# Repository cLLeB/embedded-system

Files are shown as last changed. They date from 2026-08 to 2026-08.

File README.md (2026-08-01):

# Smart Socket with Adaptive Time-of-Use Scheduling

**Project #38** — Arduino Uno. Cuts wall power when a charging device reaches full charge,
so it never trickle-charges and the battery lasts longer.

Status: **working on real 230 V mains.** 123/123 core tests passing, 41% flash / 40% RAM on
the Uno. Confirmed on hardware: a laptop charged to 95%, the socket detected the taper, cut
wall power and latched.

**Build it by following [`docs/FINAL_BUILD.md`](docs/FINAL_BUILD.md)** — that is the current
guide, step by step from bare parts to a working socket. `BUILD_GUIDE.md` and
`docs/STAGE2.md` describe the earlier low-voltage bench rig (18650 + resistor bank) that was
used to prove the firmware, and are kept for the reasoning only.

---

## Open it in Arduino IDE

1. **File → Open…** → select `SmartSocket/SmartSocket.ino`
2. **Tools → Board →** Arduino AVR Boards → **Arduino Uno**
3. **Sketch → Verify**

That is the whole migration. No project files to convert, no paths to fix. The `src/`
subfolder compiles automatically — that is a standard Arduino sketch layout, not a trick.

### The one dependency

**LiquidCrystal_I2C** (already installed on this machine, v1.1.2).

On any other machine: **Tools → Manage Libraries…** → search `LiquidCrystal I2C` → install
the one by *Frank de Brabander*.

Everything else — the algorithm, the state machine, the maths — is in this repo. No other
libraries.

---

## Wiring

| Uno pin | Connects to | Notes |
|---|---|---|
| **A0** | ACS712 `OUT` | analog signal |
| **5V** | ACS712 `VCC`, LCD `VCC`, relay `VCC` | |
| **GND** | ACS712 `GND`, LCD `GND`, relay `GND` | all grounds common |
| **A4** | LCD `SDA` | fixed I2C pin on the Uno |
| **A5** | LCD `SCL` | fixed I2C pin on the Uno |
| **D2** | Button 1 → other leg to **GND** | NEXT (cycle screens) |
| **D3** | Button 2 → other leg to **GND** | ACTION (reset / hold to force off) |
| **D7** | Relay `IN` | |
| **D8** | Buzzer `+` | buzzer `−` to GND |

**Buttons need no resistors.** They use the Uno's internal pull-ups, so each button just
bridges its pin to GND.

The **load** passes through the ACS712's screw terminals (in series) and through the relay's
COM/NO contacts.

### If the relay behaves backwards

Most cheap 1-channel boards are active-LOW, which is the default. If yours clicks the wrong
way, set `RelayActiveLow = false` in `SmartSocket/src/hal/HalPins.h`.

### If the LCD stays blank

The backpack address is usually `0x27`, occasionally `0x3F`. Change `LcdI2cAddress` in
`SmartSocket/src/core/Config.h`. If it is lit but shows nothing, turn the contrast
potentiometer on the back of the backpack.

---

## AC or DC — read this before wiring

Near the top of `SmartSocket.ino`:

```cpp
#define SENSOR_MODE_AC 1   // 1 = 230 V mains (true RMS)   0 = low-voltage DC bench test
```

This is **not** a cosmetic setting. AC current is a sine wave that averages to roughly zero
regardless of load, so the two modes use genuinely different maths:

- **AC (1)** — samples across whole 50 Hz cycles and computes true RMS. Correct for Ghana
  mains. **This is the default, and what the finished socket runs.**
- **DC (0)** — averages samples. For the old low-voltage bench rig only.

Run DC mode on mains and the socket reads an empty socket while a laptop charges. Run AC
mode on DC and it reads noise. **Match it to what you actually wired.**

## Safety

**230 V AC can kill you.** The mains side of this project is a genuine shock and fire
hazard, and no amount of firmware changes that.

- Bench-test on **low-voltage DC** first (`SENSOR_MODE_AC 0`).
- Mains work belongs in a proper enclosure, with adequate spacing, under supervision.
- Never work on it live.

The firmware fails safe — the relay is opened before anything else at boot and on any fault
— but firmware cannot make mains wiring safe.

---

## Using it

On boot the LCD shows `Calibrating...` for a moment while the sensor's zero point is
measured. Then it sits at `READY` with power on, waiting.

Plug a device in → short beep → `CHARGING`, with live current and elapsed time. When the
device fills up and its draw tapers off, the socket confirms the drop is real, cuts power,
beeps three times, and shows:

```
FULL - POWER CUT
Press ACTION
```

It **stays** cut. It will not re-arm on its own — auto-rearming would restart the exact
trickle charging this project exists to prevent. Press ACTION to re-arm.

If you re-arm without unplugging, the socket notices the device is still full (it never
draws a real charging current) and cuts it again after about a minute, rather than
trickle-charging it forever.

**Buttons**

| Action | Effect |
|---|---|
| **NEXT**, tap | Cycle screens: Status → Detail → Stats |
| **ACTION**, tap | Clear a cutoff or fault, re-arm |
| **ACTION**, hold 1.5 s | Force power off / back on |

**Screens**

```
Status              Detail              Stats
CHARGING   1.24A    Cut at     0.60A    Cutoffs        7
02:15:33  pk2.00    Taper 30%    n=7    Saved     12h30m
```

---

## What "adaptive" means here

The title says *time-of-use*, but the parts list has no RTC — the board cannot know the
clock time, let alone electricity tariff hours. The brief's description never mentions
tariffs either. It describes exactly one behaviour: measure the power, catch the drop that
means full, cut the wall.

So the *time of use* being adapted to is **the device's**, and *adaptive* means it learns:

- **Within a session** — the cutoff threshold is a fraction of the peak current this device
  actually drew, so it scales itself to a phone (~0.5 A) or a laptop (~2 A) with nothing to
  configure.
- **Across sessions** — after each successful cutoff it records where the taper really
  happened and blends it into a learned value in EEPROM. Over a few charges it converges on
  *your* device's real taper point.

Full reasoning in `docs/superpowers/specs/2026-07-17-smart-socket-design.md`.

---

## How the code is laid out

```
SmartSocket/
  SmartSocket.ino        wires the hardware to the logic; setup() and loop()
  src/core/              the logic. No Arduino.h anywhere. Tested on the PC.
    ChargeAnalyzer       the full-charge algorithm
    SocketController     the state machine that owns the relay
    CurrentMath          ADC counts -> milliamps, integer RMS
    UiPresenter          state -> two 16-char lines
    ProfileCodec         EEPROM record framing + CRC
    ButtonDebouncer, BuzzerDriver, Format, Config, Types, Interfaces
  src/hal/               the hardware. The only place Arduino.h appears.
test/                    95 tests + fakes. Arduino IDE never sees this folder.
docs/                    design spec
```

The core talks to hardware only through interfaces (`src/core/Interfaces.h`). That is what
makes two useful things possible at once: hardware can be swapped by touching one file in
`src/hal/`, and the whole algorithm can be tested with a fake clock — a three-hour charge
session runs in microseconds, so the 90-second confirmation window costs nothing to test.

## Running the tests

```powershell
powershell -ExecutionPolicy Bypass -File test\run_tests.ps1
```

Needs Visual Studio Build Tools with the C++ workload (already installed here). No test
framework to install.

The script compiles `src/core` **only** — never `src/hal`. That is deliberate: if anyone
ever adds an Arduino include to the core, the tests stop compiling and the mistake surfaces
immediately instead of at migration time.

## Tuning

Everything adjustable is in `src/core/Config.h`. The two that matter:

| Constant | Default | Meaning |
|---|---|---|
| `TaperConfirmMs` | 90 s | How long current must stay low before cutting. **Lower is dangerous** — it is the guard against cutting a laptop's power on a momentary dip. Raising it only wastes a little energy. |
| `TaperRatioDefaultPct` | 30 % | Starting cutoff point as a fraction of peak, before anything is learned. |
| `TaperMarginPct` | 130 % | How far the cutoff threshold sits above the *learned* ratio. **Do not set this to 100.** The margin is what stops the learning from eating itself — see the comment on it in `Config.h`. |

## Known limits — all measured, not assumed

- **It cannot see a phone.** Measured on this hardware: a phone charging draws **0.02 A** on
  230 V, which is the same as an empty socket reads. 20 mA is 0.4% of the ACS712-**5A**'s
  range and 0.76 of one ADC count, so no threshold can separate the signal from the noise.
  Laptop-class loads (0.13–0.16 A) work reliably. This is the specified sensor's resolution,
  not an algorithm fault — the same firmware on a 1 A part, or a shunt and INA219, resolves
  both. `ICurrentSensor` exists so that swap costs one file.
- **Resolution is better than the datasheet arithmetic suggests.** One ADC count is 26 mA,
  but the AC RMS window averages ~500 samples, and the measured noise pedestal on an empty
  socket is **under 0.02 A**. Averaging drives quantisation noise below a single count.
- **The adaptive learning is currently inert.** `TaperFloorMa` (100 mA) is larger than the
  peak-derived threshold at these currents, so the floor decides every cutoff and the learned
  ratio never changes the outcome. The learning is correct and tested; it just has no room to
  act at 230 V with this sensor. On the 3.7 V rig, where peaks were 370 mA, it governed.
- **One profile.** The socket learns one device profile, not one per device. Alternating
  devices makes the learned ratio drift between them. The within-session peak-scaling still
  handles both correctly; only the cross-session learning blurs.
- **The relay is the weak part.** A switch-mode charger's inrush is tens of amps for a few
  milliseconds, and a 10 A relay switching into that repeatedly can micro-weld its contacts.
  The firmware now detects this (see below) rather than claiming to have cut power it hasn't.

## What makes it "smart" beyond the cutoff

- **Automatic recovery.** The sensor is downstream of the relay, so an open relay leaves the
  socket blind — it cannot tell an empty socket from a full laptop. Rather than demand a
  button press, it closes the contacts for 8 s every 15 min (device still present) or 60 s
  (socket empty) and resumes only on a real charging current. Not auto-rearming: it stays
  closed only on positive evidence.
- **Relay verification.** `setClosed(false)` is a command, not a measurement. The socket keeps
  sampling while cut, and if current is still flowing 3 s later it raises `! RELAY STUCK !`
  instead of displaying `FULL - POWER CUT` over a live outlet.
- **It cannot silently freeze.** `Wire` has a 25 ms timeout so I2C noise from the relay
  cannot lock the bus, and a 4 s watchdog resets the chip if `loop()` ever stops — on reset
  the relay is opened before anything else. A hang used to leave the relay wherever it was,
  which on a mains socket means power stuck **on**.
- **The zero offset is tracked, not calibrated once.** The ACS712's offset drifts with
  temperature and rail loading; frozen at boot it walked far enough in two minutes to fake a
  0.10 A load on an empty socket. Each 60 ms window now re-derives it from the sample mean,
  which over whole mains cycles is the offset whether a load is present or not.

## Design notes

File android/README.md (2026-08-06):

# Smart Socket — Android app

Talks to the socket over Bluetooth Classic (SPP), shows what it is doing, and
tells it when to cut power.

**Runs with no hardware.** The connect screen has a demo that drives every screen
from a simulated socket, so the app can be developed and shown before an HC-05
exists.

---

## Build

```powershell
cd android
.\gradlew.bat assembleDebug
```

The APK lands in `app/build/outputs/apk/debug/app-debug.apk`.

Toolchain: JDK 17+, Gradle 8.11.1, AGP 8.9.1, Kotlin 2.0.21, compileSdk 35,
minSdk 26. `local.properties` points at the SDK.

---

## What it does

| | |
|---|---|
| **Live status** | State, current, peak, and how close the current is to the cutoff threshold |
| **Control** | Cut power, re-arm, probe now — the same three commands the buttons give |
| **Charge limit** | Stop charging **this phone** at 80 / 90 / 100% |
| **Notifications** | Tells you when power was cut, even with the app closed |
| **History** | Every cutoff, with peak, taper point and duration, plus a chart |
| **Export** | The history as a CSV, out through the share sheet |
| **Reconnects itself** | Rebuilds a dropped link for about eight minutes before giving up |
| **Demo mode** | A simulated socket, for when the real one is in another room |

### The charge limit is the point

A phone charging on 230 V draws about **20 mA**, which is inside the ACS712-5A's
noise. The socket genuinely cannot tell a charging phone from an empty outlet —
see "Known limits" in the root README.

But the phone knows its own battery. So the app watches `BatteryManager`, and
when the level crosses the limit it sends `C`. The socket stops having to
*infer* the charge state because it is *told*.

An 80% limit is also what battery-longevity practice recommends, which is the
premise of the whole project.

---

## Architecture

```
data/
  SocketStatus.kt     the model, and SocketState mirroring Types.h ordinals
  StatusParser.kt     decodes one "S,..." line, or returns null
  SocketTransport.kt  the interface
  BluetoothTransport  real link, RFCOMM to an HC-05
  MockTransport       a socket that exists only in software
  ReconnectPolicy.kt  how long to wait before the nth retry
  HistoryStore.kt     the flat file
  HistoryCsv.kt       history rendered for a spreadsheet
  HistoryExport.kt    that CSV into a share intent
ui/
  Theme.kt            the palette
  Components.kt       the shared pieces
  *Screen.kt          splash, onboarding, connect, dashboard
SocketViewModel.kt    state, battery watching, command dispatch
```

### Tests

```powershell
cd android
.\gradlew.bat :app:testDebugUnitTest
```

27 plain JVM tests, no emulator and no Robolectric. Everything worth testing —
the wire format, the reconnect schedule, the export — was written with no
Android in it so that it could be tested this way, which is the same split that
lets the firmware's `src/core` run on a PC.

**`SocketTransport` has two implementations for the same reason the firmware has
`ICurrentSensor`:** so the thing above it can be built and tested without the
hardware below it. `MockTransport` is not a stub returning canned values — it
runs the real sequence (settle, charge, taper, cut, wait, probe) at 20× speed,
which also makes states that are slow to reach on real hardware reachable in
seconds.

### Parsing is strict on purpose

`StatusParser` returns `null` for anything it does not fully understand. A
Bluetooth link drops mid-line every time the phone moves out of range, so partial
and corrupt lines are the normal case — and a half-parsed line would show a
number that never existed.

### An open socket is not a Smart Socket

`BluetoothTransport.connect` does not report success when the RFCOMM socket
opens. It sends `?` and waits for one line it can parse, up to three times.

Every bonded device that speaks SPP accepts a connection, and a swapped TX wire
or a module left at the wrong baud rate connects *perfectly* and then says
nothing at all. Without the handshake that arrives as a dashboard full of zeroes
with no clue which of the two it was. With it, the two cases are told apart by
whether any bytes arrived before the timeout:

| What happened | What the user is told |
|---|---|
| No bytes at all | Check `TXD` → Arduino pin 0, and that the socket is powered |
| Bytes, but nothing parses | Almost always the baud rate — the firmware uses 9600 |

### Reconnecting

A dropped link is rebuilt on a schedule that doubles from 2 s to a one-minute
ceiling, for twelve attempts — about eight minutes. Two cases pull in opposite
directions: a radio glitch wants a retry immediately, and someone who walked
into another room wants one much later. The ceiling serves the second without
making the first wait.

It **gives up** rather than retrying forever, and posts a notification when it
does. A foreground notification the user cannot dismiss, sitting over a socket
that has been switched off at the wall, is worse than an honest "lost it".

`LinkState.Reconnecting` is a separate state from `Connecting` because the two
mean opposite things to the UI: a reconnect must **not** throw the user back to
the device picker and must **not** release the foreground service. The dashboard
keeps the last readings on screen, labelled as the last ones, and disables the
command buttons — a button that looks like it worked and did not is worse than a
dead one on a device that switches mains.

---

## Design

**Gold on black.** Three golds, four blacks, and warm off-white rather than pure
white — `#FFFFFF` against gold reads cold and makes the gold look green.

**Dynamic colour is deliberately disabled.** On Android 12+ `dynamicDarkColorScheme`
derives the palette from the user's wallpaper, which usually lands on Material's
lavender-purple default. That would repaint the app in someone else's colours.

**No ripples.** Material's default ripple is a grey wash that reads as a smear on
gold; the buttons signal touch with colour instead.

The one chart is the taper bar on the dashboard — the whole product is "watch
this fall past that line", and a number alone does not show how close it is.

---

## Bluetooth notes

- **Classic SPP, not BLE.** An HC-05 is a Bluetooth 2.0 device. This will never
  work on iOS, which blocks SPP without MFi certification
- **Pair in Android's settings first.** The app lists bonded devices; it does not
  run discovery. Default HC-05 code is `1234` or `0000`
- **Android 12+ needs runtime `BLUETOOTH_CONNECT` / `BLUETOOTH_SCAN`.** Below 31
  the legacy manifest permissions are granted at install, so the request is
  skipped rather than failed — most tutorials predate this split and get it wrong

---

## Staying alive in the background

`SocketRepository` is held by the **Application**, not a ViewModel. That is the
whole trick: a link owned by a ViewModel dies with the screen, and can only
notify someone already looking at it.

`SocketService` is a foreground service that keeps the process alive while a
connection is up. It does not own the link — it exists so Android does not kill
the process, and so there is something to look at while it runs. Started on
connect, stopped on disconnect, because a notification the user cannot dismiss
should only be there while it is buying something.

Android 14 requires a foreground service to declare a type and hold the matching
permission; `connectedDevice` is the honest one here.

`SocketRepository` is also the only place that watches for **transitions**
rather than state — a cutoff notification has to fire on the edge into `Cutoff`,
once, not on every status line that happens to say `Cutoff`.

## History without Room

`HistoryStore` writes comma-separated lines to a file in `filesDir`, newest
first, capped at 60.

Room would bring the KSP plugin, a schema, a DAO and migrations for a table with
four integer columns that will never hold more than 60 rows. The cost is all
ceremony. Reads are one `readLines`, writes one `writeText`, and the format is
legible if anyone wants to look at it.

The chart is bars, not a line: each charge is a discrete event, and a line
between them would imply values in the gaps that were never measured.

**Export** writes the same rows to the cache directory as a CSV and hands it out
through a share intent, so it can go to email, Drive, or anything else with no
storage permission on any Android version. Two time columns: an ISO one for a
human and a millisecond one for a spreadsheet that will not parse it. Rows run
**oldest first**, the reverse of the screen — the newest charge belongs at the
top of a list, but a column a spreadsheet is going to plot has to run forwards.

## Not built yet

- **Connecting to real hardware has never been tested.** The HC-05 is here and
  wired but the first end-to-end run has not happened. Everything else runs

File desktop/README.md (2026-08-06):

# Smart Socket — Windows app

The desktop companion. Same socket, same wire format, same gold-on-black as the
phone app, plus the one thing a laptop can do that a phone cannot: cut power at
**its own** battery percentage.

---

## Why this exists when the socket already works

The socket cuts power on its own. It watches the charge current taper and opens
the relay when it falls far enough below the peak — no app, no phone, no PC.
That is the whole safety-critical path and it is finished.

What it cannot do is know *what percentage* that taper happened at. On a laptop
the taper lands wherever the charger decides, typically the high nineties.

If what you want is to stop at **80%** for the sake of the battery's lifespan,
only Windows knows when that is. So this app asks Windows and sends the cut.

Both cutoffs run at once and do not fight: whichever condition is met first
cuts, and the firmware ignores a `C` for a state it is already in.

| Device | What cuts the power |
|---|---|
| Laptop | The socket's current sensing, **or** this app at your exact percentage |
| The phone running the Android app | That app, at its battery limit |
| Anything else | The socket's current sensing only |

---

## Build and run

Needs the .NET 8 SDK. Nothing else — no Visual Studio.

```powershell
# All 30 core tests. No hardware, no UI, runs in under a second.
dotnet test tests\SmartSocket.Core.Tests\SmartSocket.Core.Tests.csproj

# Debug run.
dotnet run --project src\SmartSocket.App

# The thing you hand to somebody: one self-contained .exe, no runtime needed.
dotnet publish src\SmartSocket.App\SmartSocket.App.csproj -c Release -o dist
```

The published `dist\SmartSocket.exe` is about 68 MB because it carries the .NET
runtime and WPF inside it. That is the deliberate trade: nothing to install, no
"please install .NET 8" step in front of somebody marking the project.

---

## The architecture rule, again

**`SmartSocket.Core` must never reference anything Windows.**

It targets plain `net8.0`, not `net8.0-windows`, so the compiler enforces it —
the same trick as the firmware's `src/core` never including `Arduino.h`, and the
Android app's data layer never importing Android.

That is what lets the wire format, the charge session, the reconnect schedule
and the CSV export be tested with no window, no COM port and no socket.

```
desktop/
  src/SmartSocket.Core/     plain net8.0. Parser, session, reconnect, CSV.
  src/SmartSocket.App/      net8.0-windows. WPF, serial, tray, Win32 battery.
  tests/SmartSocket.Core.Tests/   30 tests, ported case for case from Kotlin.
```

The tests are deliberately ports of the Android app's tests, assertion for
assertion. Two clients that disagree about the wire format would show different
numbers for the same socket, and the tests are what stop that happening
quietly.

---

## Connecting

Both routes to the socket are a COM port at 9600, so there is one transport:

- **USB cable** — the Uno enumerates directly through its CDC/CH340 driver.
- **HC-05** — pair it in Windows Bluetooth settings first. Windows then exposes
  an *outgoing* virtual COM port for it, which is the one to pick.

**An open port is not a Smart Socket.** Windows will happily open a port
belonging to a printer or a GPS dongle, so connecting is not finished until the
socket has answered a `?` with a line the app can parse. The three ways that can
fail are reported separately because they have different fixes:

| The app says | What is wrong |
|---|---|
| "already open in another program" | Close the Arduino IDE's Serial Monitor |
| "opened but never sent anything" | Wrong port, or the socket is not powered |
| "sending data this app cannot read" | Baud rate. The firmware uses 9600 |

Opening a COM port asserts DTR, which **resets the Uno**. That is wanted — it
puts the firmware in a known state — but it is why the handshake tolerates
several seconds of silence before giving up.

---

## Closing the window does not stop it

The window is a view, not the app. Closing it hides it to the tray, because a
socket being watched is the normal state and a window on screen is not. The tray
icon carries the current state in its tooltip, offers **Cut** and **Re-arm**
directly, and **Quit** is the only thing that actually stops it.

This is the desktop counterpart of the phone app's foreground service, and it
exists for the same reason: a cutoff an hour away is no use if it only fires
while somebody is looking at the screen.

Balloon notifications fire on cutoff, on a stuck relay, on a lost link, and when
the app itself cut at your battery limit.

---

## What it stores, and where

`%APPDATA%\SmartSocket\`

| File | What |
|---|---|
| `settings.json` | Battery limit, whether to cut at it, last port used |
| `history.csv` | Completed charges, in the same four-field encoding the Android app writes |

The history encoding is shared deliberately: a file from the phone can be
dropped in here and read, and the exported spreadsheet has identical columns
from both apps, so exports can be concatenated.

---

## Known limits

- **Windows only.** WPF and `GetSystemPowerStatus` are both Win32. The `Core`
  project is portable; nothing above it is.
- **A desktop PC has no battery**, so the percentage cutoff has nothing to act
  on. The app says so and disables the control rather than showing 0%.
- **Reconnect gives up after about eight minutes** (`ReconnectPolicy`), rather
  than retrying forever. A tray icon claiming to watch a socket switched off at
  the wall is worse than an honest "lost it".
- If Windows will not report the battery percentage it returns 255, which the
  app treats as "unknown" and refuses to act on. Guessing there would cut power
  to a machine whose charge it does not know.

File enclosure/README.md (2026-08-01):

> ## ⚠ THIS FILE IS OUT OF DATE — DO NOT PRINT FROM IT
>
> It describes the earlier single-deck box with bezel plates and an 18650
> bracket. The enclosure was redesigned for the 230 V build: two decks split by
> a screwed-down shelf, the socket faceplate mounted in the lid, and the rocker
> snapped straight into the base's front wall with no bezel.
>
> **Print three files from `stl_slim/`: `SmartSocket_Base.stl`,
> `SmartSocket_Lid.stl`, `SmartSocket_Shelf.stl`.** `SwitchPlates` no longer
> exists in that folder.
>
> The authoritative sources are `build_slim.log` (what was actually exported)
> and the docstring at the top of `smart_socket_enclosure.py`. Assembly steps
> are in `../docs/FINAL_BUILD.md` PART 10.

# Smart Socket Enclosure — Group 38

Parametric enclosure for the Arduino Uno "Smart Socket with Adaptive
Time-of-Use Scheduling" build. Everything is generated from
[smart_socket_enclosure.py](smart_socket_enclosure.py) — the STLs are outputs,
never edit them by hand.

Needs a **180 × 180 mm bed** or larger.

---

## 0. Two versions — pick one at the print shop

Both come from the same script and the **same verified design**. `slim` only
thins the outer shell; every component position, hole pattern and internal
clearance is identical, confirmed by measuring both sets of meshes.

| | `stl/` — standard | `stl_slim/` — slim |
|---|---|---|
| Wall / floor / lid | 2.4 / 3.0 / 2.6 mm | 2.0 / 2.6 / 2.2 mm |
| Assembled size | 172.8 × 158.8 × 45.6 mm | 172.0 × 158.0 × 44.8 mm |
| **Interior (identical)** | **168 × 154 × 40 mm** | **168 × 154 × 40 mm** |
| Base + lid + bezels | **284 g** | **243 g** |
| At 2.50 GHS/g | **~710 GHS** | **~608 GHS** |

**Slim saves about 100 cedis and gives up nothing you can feel** — 2.0 mm walls
are still five extrusion lines thick, which is plenty for a box that sits on a
bench. Interior height stays at 40 mm in both, because that gap is what keeps
the LCD hanging off the lid clear of the jumper wires standing up on the
breadboard. That is the one dimension not worth trading for filament.

Those weights are solid model volume. With 20 % infill the slicer will report
roughly 15 % less — **ask the printer for his slicer's quote before he starts.**

---

## 1. Print these

Pick **one** folder — `stl/` or `stl_slim/` — and take all three files from it.

| File | What | Standard | Slim | Orientation |
|---|---|---|---|---|
| `SmartSocket_Base.stl` | Tray | ~195 g | ~168 g | As-is, floor on the bed |
| `SmartSocket_Lid.stl` | Top panel | ~80 g | ~67 g | As-is, **already flipped** |
| `SmartSocket_SwitchPlates.stl` | 3 rocker bezels | ~9 g | ~8 g | As-is, flat |

`SmartSocket_FitCheck.stl` is an optional ~39 g test coupon (section 2). Print
it first if you can afford it; skip it if you can't.

`SmartSocket_Assembly.stl` is for looking at only — **do not slice it.** It is
the base and lid fused into one solid, which is exactly what a printer means
when he asks for the model "in parts".

**No part needs support material.** Both large parts print flat. Don't rotate
anything in the slicer; the lid is already exported outer-face-down so its
bosses point up and the engraving lands on the build plate (which is what makes
it come out crisp).

### Slicer settings

- Layer height **0.2 mm**, nozzle 0.4 mm
- **4 perimeters** — walls come out fully solid in either version
- 5 top / 5 bottom layers, 20 % infill
- **Brim on the base** — it's a big flat part and the corners like to lift

---

## 2. Print the fit-check coupon first

This is the whole point of the coupon: it is 39 g and about 1½ hours, against
275 g and most of a day for the real thing. It carries every fit on the
enclosure at the exact modelled sizes:

| On the coupon | Check |
|---|---|
| 4 tall bosses in a rectangle | Arduino Uno drops on, all 4 holes line up |
| Large L-bracket pocket | Relay module sits inside and the lips hold it down |
| Small L-bracket pocket | ACS712 sits inside |
| Long L-bracket pocket | 18650 holder drops in and lifts back out |
| 4 short bosses + window | LCD screws on and all 32 characters are visible |
| Square collar + round hole | Tactile button body seats, plunger pokes through |
| Round collar + 7 small holes | Buzzer seats |
| Boss with a pilot hole | An M3 screw bites without splitting the boss |
| Countersunk hole | An M3 countersunk head sits flush |

If anything is tight or loose, change the matching constant in the script
(section 3, each one is labelled) and re-run. Don't file the real print.

---

## 3. Where everything goes

Origin is the **inside front-left corner** of the tray; "front" is the edge
nearest you at the bench, the one with the two rows of vent slots.

| Part | X (mm) | Y (mm) | How it is held |
|---|---|---|---|
| Breadboard (830 pt) | 1.5 – 166.5 | 10 – 65 | Side walls + 2 ribs; use its own adhesive backing |
| Arduino Uno | 1.5 – 70.1 | 71 – 124.4 | 4 × M3 into the floor standoffs |
| Relay module | 76.5 – 126.5 | 71 – 97 | Snaps under the bracket lips |
| ACS712 | 135 – 148 | 71 – 102 | Snaps under the bracket lips (turned 90°) |
| 18650 holder | 76.5 – 154.5 | 111 – 132 | Drops into brackets, no lips — cell stays swappable |
| Rocker switch | back wall, 45 mm from the left | | Bezel plate |

**The Arduino's USB and barrel jack face the left wall** and come out through
the wide opening there — you can reflash without opening the box.

On the lid: LCD at the front-left, MODE and SET at the front-right, buzzer
between them, vents and the `GROUP 38` engraving across the back.

---

## 4. Hardware you need

- **6 × M3 × 12 countersunk** — lid to base
- **4 × M3 × 8 pan head** — Arduino to the floor standoffs
- **4 × M3 × 6 pan head** — LCD to the lid bosses
- Hot glue — the two buttons, the buzzer, and the switch bezel

Self-tapping M3 is ideal, but ordinary M3 machine screws cut their own thread
in PLA perfectly well. All pilot holes are 2.4–2.6 mm.

---

## 5. Assembly order

1. Try the rocker in each of the three bezel plates; keep the one that fits
   (`small`, `standard`, or file the `blank` to shape). Press it into the
   back-wall opening from the outside, dab of glue.
2. Screw the Arduino to the four floor standoffs.
3. Press the relay and the ACS712 down into their bracket pockets until the
   lips catch the PCB edges. Drop in the battery holder.
4. Stick the breadboard down between the two ribs.
5. Fit the LCD to the lid bosses. Hot-glue the two buttons and the buzzer into
   their collars from underneath.
6. **Wire the lid parts with ~150 mm of slack** so the lid can be lifted off
   and set beside the box without pulling anything loose.
7. Wire everything else, then close with the six countersunk screws.

---

## 6. Regenerating after a change

Every dimension is a named constant at the top of the script. Change it and
re-run:

```bash
"C:/Program Files/FreeCAD 1.1/bin/freecadcmd.exe" smart_socket_enclosure.py
```

For the slim version, set `SMART_SOCKET_SLIM=1` first — same script, one design:

```bash
SMART_SOCKET_SLIM=1 "C:/Program Files/FreeCAD 1.1/bin/freecadcmd.exe" smart_socket_enclosure.py
```

Output goes to `stl/` (or `stl_slim/`) and a report to `build.log`
(or `build_slim.log`). The script runs a layout
check **before** it writes anything — overlapping modules, a part fouling a
screw boss, something too tall for the interior, the LCD bosses eating into the
window, no clear volume behind the rocker — and refuses to export if any of
those fail. If you move a component and it complains, believe it.

---

## 7. Design notes — why things are the way they are

**Dimensions are graded by confidence, and the mounting method follows.**
The Arduino outline and its four mounting holes, and the LCD's 75 × 31 hole
pattern, are published values — those get exact bosses, and they land within
0.001 mm in the exported STL. Relay, ACS712 and battery-holder outlines vary
between vendors, so those get L-shaped corner brackets with 0.8 mm of slack:
the module only has to land inside the corners, so being 1.5 mm off nominal
costs nothing.

**The Arduino connector opening is one wide 55 × 15 mm slot, not two tight
cutouts.** The board's position is exact because the standoffs fix it, but the
USB and barrel-jack positions *along* that edge are not something worth betting
a 275 g print on. One opening clears both regardless.

**The rocker switch is on a replaceable bezel.** It's the one part whose size
couldn't be pinned down — the common families (KCD11, KCD1-101, KCD3) need very
different cutouts. So the back wall gets a generous 30 × 24 mm opening and a
2 g bezel plate carries the actual cutout. Wrong guess costs ten minutes, not
the enclosure.

**The LCD window is 67 × 23 mm — sized to the active display area, not the
metal bezel.** A bezel-sized 72 × 26 window would run straight through the
mounting bosses, which sit only 34.5 mm from centre. The window has a 45°
chamfer on the outer face so the 4 mm depth doesn't vignette the display at an
angle; printed face-down that chamfer is self-supporting.

**Height is 45.6 mm against the old model's 75 mm.** The old enclosure was
~378 g and had no internal mounting features at all — just four corner posts
for the lid, with every board left to rattle around loose. It also had a
52 × 52 mm hole in the lid with nothing behind it, and the lid was fused to the
base in one STL so it couldn't be printed without cutting it up first.

**Footprint is set by the 165 mm breadboard**, which alone is 46 % of the floor.
The back strip packs the other four modules at about 70 % density — tighter
than that and there's no room to get a jumper in.

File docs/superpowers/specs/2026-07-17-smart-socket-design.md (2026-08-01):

# Smart Socket with Adaptive Time-of-Use Scheduling — Design

**Date:** 2026-07-17
**Project #38.** Target: Arduino Uno. Market context: Ghana (230 V / 50 Hz mains).

## 1. The brief, and what it actually asks for

> Construct an eco-friendly smart socket that protects battery lifespans of plugged
> electronics (like laptops or phones). It measures the power drawn; when it detects the
> plugged device's power usage drops significantly (signaling 100% full charge), it
> completely cuts wall power to prevent trickle-charging wear.

**Components:** Arduino Uno, ACS712 (5 A), Relay Module (1-ch), 16x2 I2C LCD, Tactile
Buttons, Active Buzzer, Resistors, Breadboard, Li-ion batteries with case and SPDT switch.

### Interpreting "Adaptive Time-of-Use Scheduling"

The title says "time-of-use", but the description never mentions tariffs, peak hours, or
electricity pricing, and **the component list contains no RTC** (confirmed absent from the
physical kit). Without an RTC or network, the board cannot know wall-clock time.

**Resolution (user-confirmed):** "time-of-use" means the **plugged device's** use, not the
utility's tariff clock. "Adaptive" means the socket learns each device's real charging
profile and adapts its cutoff point, instead of using a fixed timer. This needs no RTC and
matches the description exactly.

**Explicitly out of scope (YAGNI):** tariff windows, peak/off-peak deferral, WiFi, app,
cloud, multi-socket, energy billing.

## 2. Goals, in the user's stated priority order

1. **It must work.** Correct taper detection, no false cutoffs mid-charge.
2. **Migration must be easy.** Drops into Arduino IDE with no restructuring.

Everything below is subordinate to those two.

## 3. Architecture

The single most important decision: **decision logic contains no `Arduino.h`.**

```
SmartSocket/                  <- open THIS folder in Arduino IDE
  SmartSocket.ino             <- composition root: wires HAL -> core, setup(), loop()
  src/
    core/                     <- portable C++. No Arduino.h. Native-testable.
      Types.h                 enums + small value structs
      Config.h                every tunable constant (no magic numbers)
      Interfaces.h            IClock, ICurrentSensor, IRelay, IDisplay,
                              IBuzzer, IButtonSource, IProfileStore
      Format.h/.cpp           AVR-safe number/time -> text (no printf/float bloat)
      ButtonDebouncer.h/.cpp  raw pin level -> Short/Long press events
      BuzzerDriver.h/.cpp     non-blocking beep patterns
      ChargeAnalyzer.h/.cpp   THE ALGORITHM: taper detection
      SocketController.h/.cpp THE STATE MACHINE
      UiPresenter.h/.cpp      state -> two 16-char LCD lines
    hal/                      <- Arduino-only. Guarded by #if defined(ARDUINO)
      HalClock, HalCurrent (AC-RMS + DC), HalRelay, HalDisplay,
      HalButtons, HalBuzzer, HalProfileStore (EEPROM)
test/                         <- native MSVC tests + fakes. Never seen by Arduino IDE.
```

Arduino IDE compiles a sketch's `src/` subfolder **recursively** (supported since 1.6.10),
so this layout builds with zero configuration: open the folder, press Verify.

The `core` <-> `hal` split is what makes both goals achievable simultaneously. Core depends
only on interfaces, so:

- **Testing without hardware:** fakes implement the interfaces. A `FakeClock` lets a
  3-hour charge session execute in microseconds — no `delay()`, no waiting.
- **Migration:** hardware code is quarantined in `hal/`. Swapping the LCD or sensor touches
  one file and never touches the algorithm.

### Dependency rule

`core` never includes `hal`. `hal` implements `core`'s interfaces. The `.ino` is the only
place that knows about both — it constructs concrete HAL objects and injects them.

## 4. Current measurement

The ACS712 outputs a voltage centered at Vcc/2, swinging ±185 mV per amp (5 A model).

**Two engines behind one `ICurrentSensor` interface:**

- **`DcCurrentSensor`** — averages N samples. For low-voltage DC bench testing.
- **`AcRmsCurrentSensor`** — mains is a sine wave; averaging it yields ~zero regardless of
  load. Must compute **true RMS**: sample over whole 50 Hz cycles (60 ms = 3 cycles),
  subtract the zero offset, square, accumulate, sqrt, scale. The window must stay a whole
  multiple of 20 ms or partial-cycle bias makes the reading wander with phase. Three cycles
  rather than five because this loop blocks, and every millisecond in it is one `loop()`
  cannot poll the buttons.

Ghana mains is the real deployment target, so AC-RMS is the default; DC exists so the
project can be exercised safely on the bench.

**Zero-offset auto-calibration:** at boot, with the relay **open** (guaranteed no current),
average the ADC to find the true zero point. This corrects sensor and supply variation and
is far more accurate than assuming exactly 512.

**Honest accuracy note:** 10-bit ADC over 5 V = 4.89 mV/LSB; at 185 mV/A that is
**~26 mA per LSB**. Thresholds below ~50 mA are inside the noise floor and cannot be
trusted. All thresholds are set well above this. This is a real limitation of the specified
parts, not a bug.

## 5. The algorithm (ChargeAnalyzer)

Chargers are constant-current/constant-voltage: current sits high while filling, then
tapers as the battery approaches full, dropping to a trickle at ~100%.

1. **Smooth** raw readings with an EMA to reject noise.
2. **Track peak** current seen during the session — this is the adaptive baseline.
3. **Threshold** = `max(peak × effectiveTaperPct, TAPER_FLOOR_MA)`, where
   `effectiveTaperPct = clamp(learnedTaperPct × TAPER_MARGIN_PCT)`. See the learning
   section below for why the margin exists.
4. **Confirm before acting.** Current must stay below the threshold *continuously* for
   `TAPER_CONFIRM_MS` (90 s), and the session must have run at least `MIN_CHARGE_MS`
   (60 s). This is the guard against the failure that would ruin the product: cutting power
   during a momentary dip mid-charge.
5. **Distinguish unplug from full.** Both are low current. Below `UNPLUG_MA` → device
   removed, return to Idle. Below taper but above unplug → genuinely full, cut power.
6. **Catch the already-full device.** If the peak never reaches `MIN_SESSION_PEAK_MA`
   (300 mA) by `MIN_CHARGE_MS`, this was never a charge — it is a full device left plugged
   in while the socket was re-armed. Its own trickle would otherwise become the session
   peak, putting the threshold permanently out of reach. Cut it.

### The learning (what makes it "adaptive")

Two layers:

- **Within-session:** the threshold derives from the observed peak, so it self-scales to a
  phone (~500 mA) or a laptop (~2 A) with no configuration.
- **Across sessions (EEPROM):** on each successful cutoff, record
  `actualCutoffCurrent / peak`. Blend into a stored `learnedTaperPct` via EMA, clamped to
  10–60 %. The socket converges on *this* device's real taper point over repeated use.
  Sessions that never reached `MIN_SESSION_PEAK_MA` are excluded — their ratio is ~100 %,
  which is an artefact, not a device characteristic.

#### Why the threshold sits above the learned ratio

The cutoff threshold is the learned ratio **times `TAPER_MARGIN_PCT` (130 %)**, not the
learned ratio itself. This is load-bearing, and the first version of this design got it
wrong.

The learned value comes from the current at which a cutoff happened — which is, by
construction, always *below* the threshold that triggered it. Feed that straight back and
the threshold ratchets downward every session, converging onto the device's trickle
current. At that point `current < threshold` can never be true again and **the socket
silently stops cutting off forever**, with nothing on the display to indicate it. It took
about six charges of the same device.

Holding the threshold a fixed margin above the learned value turns an absorbing fixed point
into a stable one: the learned ratio settles on the device's true taper, and the threshold
settles just above it, still reachable. Covered by
`test_ChargeAnalyzer.cpp: learning_converges_and_keeps_working_over_many_sessions`, which
runs 40 consecutive sessions — a single-session test cannot see this class of bug.

EEPROM record is versioned and CRC-16 protected; a failed CRC falls back to defaults rather
than acting on garbage.

## 6. State machine (SocketController)

```
Calibrating --(zero offset captured, relay open)--> Idle
Idle        --current > PLUG_MA sustained-------> Settling   (relay closed, listening)
Settling    --after SETTLE_MS--------------------> Charging   (ignores inrush transients)
Charging    --analyzer confirms taper-----------> Cutoff     (relay OPEN, latched, alarm)
Charging    --current ~0 sustained--------------> Idle       (unplugged)
Charging    --current > OVERCURRENT_MA----------> Fault      (relay OPEN, alarm)
Cutoff      --button ACTION short---------------> Idle       (relay closed, re-arm)
Fault       --button ACTION long----------------> Idle
any         --button ACTION long----------------> ManualOff  (user override)
```

**Cutoff latches.** It does not auto-rearm — auto-rearming would re-start the trickle
charging the product exists to prevent. Only a human clears it.

## 7. Hardware map (Arduino Uno)

| Pin | Role | Notes |
|-----|---|---|
| A0 | ACS712 OUT | analog |
| A4 / A5 | I2C SDA / SCL | fixed on Uno; LCD backpack |
| D2 | Button NEXT | `INPUT_PULLUP`, button to GND |
| D3 | Button ACTION | `INPUT_PULLUP`, button to GND |
| D7 | Relay IN | active-LOW configurable in Config.h |
| D8 | Active buzzer | drive HIGH = sound |

Buttons use internal pull-ups, so no external resistors are needed for them.

## 8. UI

Screens cycle with NEXT:

- **Status** — state + live current; elapsed time + session peak
- **Detail** — cutoff threshold, learned ratio, session count
- **Stats** — lifetime cutoffs, total time saved

Cutoff and Fault take over the display regardless of screen, because they are the states
the user must act on.

Buzzer (active type — on/off only, no `tone()`): 1 short beep on plug detect, 3 beeps ×2 on
cutoff, continuous slow beep on fault. All non-blocking.

## 9. Error handling

- EEPROM CRC failure → defaults, no crash.
- Sensor reading implausible (beyond ACS712 range) → Fault, relay open.
- Overcurrent > 4.5 A (ACS712-5A limit) → immediate Fault, relay open. Checked in
  `SocketController::update()` against the **raw** reading, before the state switch — so it
  applies in every state the relay can be closed in, and trips within one sample. Checking
  it inside the analyzer would leave an over-limit load connected for the several seconds it
  takes to cross Idle and Settling; checking the smoothed value would wait for the EMA to
  climb. A protection limit must not be filtered, and must not be reachable only from one
  state.
- Relay defaults to **open** on boot until calibration completes — fail safe, never fail
  energized.

## 10. Testing

Native MSVC tests against fakes, covering: taper detection with realistic charge curves,
the mid-charge-dip false-positive guard, unplug vs. full disambiguation, overcurrent,
state transitions, button debounce/long-press, EEPROM CRC round-trip, and UI rendering
(exactly 16 chars, no overflow).

Firmware is additionally compiled for real AVR via the bundled `arduino-cli` to prove it
fits in the Uno's 32 KB flash / 2 KB SRAM.

## 11. Safety

The mains path is genuinely lethal. 230 V AC through an ACS712 on a breadboard is a shock
and fire hazard. Bench-test on low-voltage DC. Any mains work requires a proper enclosure,
adequate creepage/clearance, and supervision. The firmware fails safe (relay open), but
firmware cannot make mains wiring safe.

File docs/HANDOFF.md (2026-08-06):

# Handover

You have inherited a working smart socket and an Android app that has never met
the radio it was written for. This is what is done, what is not, and the order
to finish it in.

If you are an AI assistant picking this up: read `CLAUDE.md` first. It has the
build commands, the architecture rule, the measured hardware facts, and the six
bugs that already cost days here.

---

## 1. What already works

**On real 230 V mains, confirmed on hardware.** A laptop charged to 95%, the
socket saw the current taper, cut the wall and latched. `Cutoffs` incremented,
which is the difference between a real cutoff and the trickle-rejection path
that looks identical from the outside.

| | State |
|---|---|
| Firmware | **Done.** 129 tests, 42% flash / 47% RAM as fitted |
| Telemetry over UART | **Done and proven on hardware.** `S,...` lines confirmed once a second in the Serial Monitor at 9600 |
| Android app | **Done.** 27 tests. Battery cutoff now runs on the Application, so it survives the app being swiped away |
| Windows app | **Done.** 30 tests. Self-contained `.exe`, tray-resident, cuts at the laptop's own battery percentage |
| App ↔ real socket | **Never tested.** The HC-05 is wired; this is the one open step |
| Enclosure | Designed, verified, **not printed** |

Both clients run today with no hardware at all: open either and choose
**"Open demo"**, which drives every screen from the socket's own state machine
in software.

Built installers land in `dist/`:

| File | Install it by |
|---|---|
| `SmartSocket-1.0.apk` | Copying to the phone and tapping it. Allow "unknown sources" |
| `SmartSocket-1.0-windows.exe` | Double-clicking. Self-contained — nothing to install first |

The APK is signed with `android/keystore/smartsocket.jks`. **That keystore and
its `keystore.properties` are gitignored, and losing them means never being able
to update an installed copy of the app.** Back them up somewhere off this
machine.

---

## 2. Do these in order

### Step 1 — Flash the current firmware and prove the link over USB

**Before touching the HC-05.** The radio uses the same UART, so if this works,
the module is plug-and-go.

1. Open `SmartSocket/SmartSocket.ino`, Board → Arduino Uno, upload.
   It should report **15218 bytes (47%)**.
2. **Tools → Serial Monitor, 9600 baud.**
3. You should see a line every second:

   ```
   S,1,0,0,0,0,3,45230,1
   ```

   That is `S,<state>,<mA>,<peak>,<threshold>,<elapsedMs>,<cutoffs>,<savedMs>,<relay>`.
   State `1` is `READY` — the ordinals are the `SocketState` enum in
   `src/core/Types.h`.
4. Type **`C`** and press Enter. The relay should click, the LCD should read
   `FULL - POWER CUT`, and the state ordinal should change to `4`.
5. Type **`R`**. It should re-arm to `1`.

If that works the whole telemetry path is proven and nothing below is guesswork.

### Step 2 — Wire the HC-05

**The module on hand is a ZS-040**, six pins, with a small button. Its own label
settles the two questions that matter:

- **`Power: 3.6--6V`** — so `VCC` goes to the Uno's **5 V**. It has an onboard
  regulator.
- **`LEVEL: 3.3V`** — so `RXD` is a **3.3 V input**. The divider below is not
  optional.

Pin order, printed beside each pin. **The button is at the `EN` end**, which is
the reliable way to tell which end is which:

```
EN      <- button beside this one.   leave empty
VCC                                  + rail
GND                                  - rail
TXD                                  Uno pin 0 (RX), direct
RXD                                  divider tap
STATE                                leave empty
```

**Four wires, and one of them needs resistors.**

```
HC-05 VCC  ->  Uno 5V
HC-05 GND  ->  Uno GND
HC-05 TXD  ->  Uno pin 0 (RX)      direct
Uno pin 1 (TX)  ->  divider  ->  HC-05 RXD
```

**The divider is not optional.** The Uno drives 5 V into a pin the board itself
labels 3.3 V. Feeding it 5 V works right up until it does not, and then the
module is dead.

Build it from three of the 110 Ω resistors already in the kit, in the **upper
block**, which is empty across columns 11–17:

```
Uno pin 1 ----[110R]----+----[110R]----[110R]---- GND
   col 11       11-13   |    13-15       15 - rail
                        |
                     col 13 ---- HC-05 RXD
```

That is 5 V x 220/330 = **3.33 V**. Any pair in a roughly 1:2 ratio works;
these are the parts on hand.

The other direction needs nothing: the HC-05's 3.3 V output clears the Uno's
input threshold.

**Pins 0 and 1 are also the USB uploader's.** Unplug the HC-05's TX and RX
wires before every upload, or the upload fails.

**Do not hold the module's button while powering up.** That line is the module's
`KEY` input; holding it enters AT command mode at 38400 and the module then
looks dead. Normal power-up is data mode at 9600, which is `config::TelemetryBaud`.

### Step 3 — Pair, then connect

1. Power the socket. The HC-05's LED blinks fast when unpaired.
2. On the phone, **Android Settings → Bluetooth → pair with `HC-05`**. Code is
   **`1234`** or **`0000`**.
3. Open the app, allow the Bluetooth permission, and pick `HC-05` from the list.

**The app lists bonded devices only — it does not run discovery.** If it is not
paired in Android's settings, it will not appear.

Expect this to be the step that needs debugging, because it is the one path
nobody has run. Baud is 9600 on both sides (`config::TelemetryBaud` and the
HC-05 default). If the module was reconfigured by a previous owner, that is the
first thing to check.

**The app now tells you which failure it is.** It does not report a connection
until the socket has answered: it sends `?` and waits for one line it can parse.
Three outcomes, and they mean different things:

| The app says | It means |
|---|---|
| "Could not connect" | The RFCOMM socket never opened. Not paired, out of range, or unpowered |
| "never sent anything" | Connected fine, but silence. **`TXD` → pin 0**, or the socket is off |
| "cannot read" what it sends | Bytes are arriving but nothing parses. **Baud rate** — the firmware uses 9600 |

### Step 4 — Print and assemble the enclosure

Three files from `enclosure/stl_slim/`: **Base, Lid, Shelf.** ~340 g.
Assembly is `docs/FINAL_BUILD.md` PART 10.

Needs: M3 self-tappers (8/12/16/20 mm assortment), six M3x16 countersunk, hot
glue, and **a soldering iron** — the buttons and buzzer move onto the lid and
need six joints.

The HC-05 fits in the 18650 bay, which is dead space in the mains build.

---

## 3. What is left in the app

**One thing, and it is the one that needs the module in the room.**

| | Notes |
|---|---|
| Real-hardware testing of `BluetoothTransport` | Never run against an HC-05 |

Everything else is built. Since the handover was written:

- **A connection handshake.** An open RFCOMM socket is not a Smart Socket — the
  app now sends `?` and waits for a line it can parse before saying "connected",
  and distinguishes silence from unreadable bytes. See the table in Step 3
- **Automatic reconnection**, doubling from 2 s to a one-minute ceiling for
  about eight minutes, then giving up with a notification. The dashboard stays
  put and the foreground service stays up while it works
- **History export** as a CSV through the share sheet
- **27 JVM unit tests** — `cd android; .\gradlew.bat :app:testDebugUnitTest`

The app's architecture is what made that possible without hardware:
`SocketTransport` has two implementations, and `MockTransport` runs the real
sequence at 20x. **Build against the mock, then swap.** That is why it exists.

---

## 4. Things that will waste your time if you do not know them

- **`src/core/` must never include `Arduino.h`.** That is what lets 129 tests
  run on a PC. `run_tests.ps1` compiles core only, so a violation fails loudly.
- **Do not hardcode milliamp literals in tests.** They silently stop testing
  what they name when thresholds move. Derive from `config::`.
- **The socket cannot see a phone charging.** 20 mA on 230 V, inside the
  ACS712-5A's noise. This is not fixable in firmware — it is why the app has a
  battery-percentage cutoff.
- **Unplug the HC-05's TX/RX before every upload.**
- **The relay contacts stuck once.** A `Wire` lockup froze `loop()` with the
  relay closed; the timeout and watchdog now prevent it, and ten manual-off
  cycles passed afterwards. If "power cut" ever shows over a live outlet again,
  the firmware will now say `! RELAY STUCK !` instead of lying.

---

## 5. Safety

**230 V, and this build has no earth** — the plug lead is 2-core. Only
double-insulated (Class II) appliances. The relay switches **live**, never
neutral, and the load is on `NO` so any failure falls back to power off. Mains
never touches the breadboard.

Full rules: `docs/FINAL_BUILD.md`, "Safety".

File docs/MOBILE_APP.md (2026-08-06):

# Mobile app — specification and plan

> **Status: built.** The app lives in [`android/`](../android) — see
> [`android/README.md`](../android/README.md) for how to build it and what it
> does. The firmware side (`ITelemetry` / `HalTelemetry`) is in and tested.
>
> What remains untested is the only part that needs hardware: **connecting to a
> real HC-05.** Everything else runs today, against `MockTransport`.
>
> This document is kept as the reasoning behind the design, not as a to-do list.

Target: **Android**, native.

---

## 1. Read this first: the Uno has no radio

There is no WiFi and no Bluetooth on an Arduino Uno. Not disabled, not unused —
physically absent. **An app cannot talk to this socket until a radio is added.**

The kit contains no radio either. Every component was checked against the kit
photographs: Uno, LCD + PCF8574 backpack, relay module, ACS712, breadboard,
tactile buttons, rocker switch, 18650 + holder, header strip, jumpers, resistors,
and a KY-016 RGB LED module. Nothing with an antenna.

| Option | Cost (GHS) | Notes |
|---|---|---|
| **HC-05** — Bluetooth Classic, SPP | 40–60 | **Recommended.** Android-native, simplest stack |
| HC-06 | 40–60 | Slave only. Fine here — the socket is never the master |
| HM-10 / HC-08 | 60–90 | **BLE, not Classic.** Different Android code entirely (GATT, not a socket). Works on iOS |
| ESP-01 / ESP8266 | 40–60 | WiFi. Needs 3.3 V and level shifting |
| Replace the Uno with an ESP32 | 80–120 | WiFi *and* BLE built in. See below |

**iOS is why Classic is the right default.** Apple blocks Bluetooth SPP without
MFi certification, so an HC-05 is Android-only. That matches the target.

### The ESP32 option is smaller than it sounds — but not yet

`src/core/` is portable C++ with no `Arduino.h` anywhere, which is why 123 tests
run natively on a PC. Only `src/hal/` knows about the hardware. Porting means
rewriting five small files, not the project — and it would bring far more RAM and
flash, a much better ADC, and no pairing.

**Do not do it before the demo.** The enclosure is dimensioned around the Uno's
footprint and mounting holes.

---

## 2. What the app should do

### Tier 1 — read-only. Most of the value, least of the work.

- Live status: state, current, session time, peak
- **Notification when power is cut** — "Your laptop is charged." This is the
  actual point of a smart socket; the rest is decoration
- Charge history and graphs. The Uno has no clock and 1 KB of RAM; the phone has
  both. Let the socket stream and the phone remember
- Lifetime stats: cutoff count, time saved

### Tier 2 — control

- Force power off / on, and re-arm after a cutoff, without walking to the box
- Trigger a probe immediately instead of waiting out the interval
- Change thresholds live — taper confirm time, taper ratio, plug-detect level —
  without re-flashing

### Tier 3 — the one that actually matters

**Solve the phone-detection problem in software.**

The socket cannot see a phone charging. Measured: 0.02 A on 230 V, which is the
same as an empty socket reads, 0.76 of one ADC count. No threshold separates a
signal that size from the noise. See the "Known limits" section of the README.

**But the phone knows its own battery percentage.** Android exposes it through
`BatteryManager` in about five lines.

So: the app watches its own battery, and when it crosses a limit the user sets —
80%, 90%, 100% — it sends `C` over Bluetooth and the socket cuts power.

The socket stops having to *infer* the charge state, because it is told. An 80%
limit is also exactly what battery-longevity practice recommends, which is the
entire premise of the project.

**Build this first after the plumbing works.** It turns the hardest unsolved
problem into a feature.

---

## 3. Wire protocol

Line-based ASCII over UART at 9600. Deliberately dumb: no JSON parser on a part
with 1.2 KB of free RAM.

### Socket → app, one line per sample interval

```
S,<state>,<mA>,<peakMa>,<elapsedMs>,<cutoffs>,<savedMs>\n
```

`<state>` is the `SocketState` enum ordinal from `src/core/Types.h`. Send the
ordinal, not a string — the app has the names, the socket has 19 KB of flash left
and no reason to spend it on text.

### App → socket

| Command | Meaning | |
|---|---|---|
| `C\n` | Cut power now | built |
| `R\n` | Re-arm | built |
| `P\n` | Probe now | built |
| `?\n` | Send one status line immediately | built |
| `T<seconds>\n` | Set taper confirm time | **not built** |

`HalTelemetry::pump` accepts **single letters only**; anything longer is dropped.
`T<seconds>` was designed here and deliberately not implemented — live-editable
cutoff thresholds on a device switching 230 V is a bigger decision than it looks,
and the socket learns its own profile anyway. Adding it means teaching `pump` to
parse an argument, and making the threshold mutable in `Config.h`.

Unknown commands must be ignored, not faulted. A phone that reconnects mid-line
will send garbage.

---

## 4. Firmware work needed

**None of this exists yet.**

1. `ITelemetry` in `src/core/Interfaces.h` — `void publish(const SocketStatus&)`
   and a command-poll. **The core must not learn that Bluetooth exists**; it talks
   to hardware only through interfaces, which is what keeps it testable with fakes.
2. `src/hal/HalTelemetry.h/.cpp` — the UART implementation.
3. A fake in `test/Fakes.h`, and tests that assert commands are honoured and
   malformed input is ignored.

Budget: roughly 1.5 KB flash, ~100 bytes RAM. There is 19 KB and 1.2 KB spare.

### Two hardware gotchas

- **Hardware `Serial` is on pins 0/1, which the USB uploader also uses.** Unplug
  the HC-05 to upload. This is normal and worth documenting on the enclosure.
- **Do not use `SoftwareSerial`.** It disables interrupts while transmitting, and
  this firmware has a 60 ms blocking RMS sample window and `tone()` on Timer2. Use
  the hardware UART.

---

## 5. Android stack

| Layer | Choice |
|---|---|
| Language | Kotlin |
| UI | Jetpack Compose |
| Bluetooth | `android.bluetooth.BluetoothSocket`, SPP UUID `00001101-0000-1000-8000-00805F9B34FB` |
| Async | Coroutines + `Flow` over the input stream |
| Storage | Room, for charge history |
| Charts | Compose Canvas, or MPAndroidChart |
| Background | Foreground service + `NotificationManager` |

### Two things that will bite

- **Android 12+ requires runtime `BLUETOOTH_CONNECT` and `BLUETOOTH_SCAN`
  permissions**, not manifest-only. Most tutorials predate this and will not work.
- **Battery optimisation kills background services.** "Notify me when charging
  finishes" needs a foreground service with a persistent notification, and a
  request for battery-optimisation exemption.

---

## 6. Build order

1. **Firmware telemetry + the `C` command.** Small, testable, immediately useful.
   Verify with the Arduino IDE's Serial Monitor before any app exists
2. **Bare-bones app**: connect, show live status, one button to cut power
3. **The battery-percentage cutoff** (Tier 3)
4. Notifications, history, charts, live settings

Steps 1 and 2 are an evening each. A polished app with pairing, a foreground
service, permissions handled properly, history and charts is days.

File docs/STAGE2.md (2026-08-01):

# Stage 2 — the load, the battery, and the first real cutoff

Stage 1 is done: sensor, relay, buzzer and both buttons all work. Stage 2 adds the
thing being "charged", and gets the relay to cut it off for real.

Highest voltage anywhere: **3.7 V**. It cannot hurt you.

**The one real rule:** the battery's red wire must never touch its black wire, and
no resistor leg on one rail may touch a leg on the other rail. That is a short
across the cell. The cell gets hot, fast. Everything below is arranged so this
cannot happen by accident, as long as you keep the legs straight.

---

## What you are adding

Only **one** new thing goes into the breadboard: the resistor bank. Everything
else is four wires between screw terminals.

```
battery +  ->  relay COM screw
relay NO   ->  ACS712 screw 1
ACS712 screw 2  ->  LOAD RAIL A
11 resistors across the two load rails
LOAD RAIL B  ->  battery -
```

**None of this touches the Arduino's `+`/`−` rails.** That is different from
`BUILD_GUIDE.md` Part 9 on purpose. The ACS712's two screw terminals are
electrically separate from its `VCC`/`GND`/`OUT` pins, so the battery loop needs
no shared ground with the Uno — and keeping 0.37 A out of the Arduino's ground
rail is what removes the phantom 0.10–0.12 A reading you saw in Stage 1.

---

# PART A — Get ready

### Step A.1 — Kill the power
Unplug the USB cable from the Arduino. No lights.

### Step A.2 — Take the cell out
Lift the blue 18650 out of its holder. Set it on the far side of the table. It
stays out until Step D.2.

### Step A.3 — Count out 11 resistors
From the bag in your photo, take **11 resistors**. Check all 11 have the **same
colour bands: brown – brown – black – black – brown**. That is 110 Ω.

You should still have plenty left in the bag. The one already wired to the buzzer
on `D8` stays where it is — do not steal it.

---

# PART B — Choose the two load rails

The long strips down the top and bottom edges of the breadboard are the **rails**.
There are four of them: two along the top edge, two along the bottom edge.

### Step B.1 — Find the pair Stage 1 is using
Look at where the wire from the Arduino's **`5V`** pin lands. The rail it goes
into, and its partner right next to it, are the **Stage 1 pair**. They have your
LCD, relay and sensor `VCC`/`GND` wires in them.

**Do not touch that pair for the rest of Stage 2.**

### Step B.2 — Use the pair at the opposite edge
If Stage 1 is on the bottom edge, your load rails are the **two strips along the
top edge**. If Stage 1 is on the top, use the bottom two.

Give them names, because they are not power rails any more:

- **LOAD RAIL A** — the strip closer to the lettered rows
- **LOAD RAIL B** — the strip on the outer edge of the board

Ignore the red and blue printing. Those two strips are now just "two long
connected points".

### Step B.3 — Check they are completely empty
Run your eye along the whole length of both. **No jumper, no resistor leg,
nothing.** If anything at all is plugged into either strip, pull it out or move
the bank to the other edge.

### Step B.4 — Remember which half
Your breadboard's rails are **split in the middle**, around column 30. The left
half of a rail and the right half are **not** connected.

**Pick the right-hand half — columns 33 to 63 — and keep every single thing in
this stage inside it.**

### Step B.5 — Never bridge the two pairs
Some tutorials tell you to run a jumper from `+` to `+` across the board. **Do
not.** That would put the battery onto the Arduino's 5 V rail.

---

# PART C — Build the resistor bank

Good news: **within one rail strip, every hole is the same electrical point.** So
the exact holes do not matter — only that one leg is in RAIL A and the other is
in RAIL B, and that you stay in the right-hand half.

### Step C.1 — Bend the first resistor
Hold a resistor and bend both legs straight down, about 8 mm apart — just wide
enough to span from RAIL A across to RAIL B.

### Step C.2 — Plug it in above column 40
Push it in so:
- **one leg → LOAD RAIL A**, around **column 40**
- **the other leg → LOAD RAIL B**, straight across from it

It sits like a tiny bridge across the two strips. Push until the legs feel
gripped.

### Step C.3 — Add ten more, working to the right
Do the same again at column 41, 42, 43 … up to column 50. **Eleven resistors,
side by side, all crossing the same two strips.** They look like a row of little
fences.

### Step C.4 — The safety check
Look along the row from the end. Every resistor's two legs go **straight down**,
one into each strip.

**No leg may lean over and touch a leg from the other strip.** If two legs from
opposite strips touch, that is a dead short across the battery. Straighten
anything that leans.

(The firmware would catch it — it cuts the relay above 4.5 A within a quarter of a
second — but do not make it prove that.)

### Step C.5 — Count them
Point at each one and count out loud. **Eleven.** Every threshold in the firmware
is positioned against that number, so 10 or 12 will change what you see later.

---

# PART D — The four wires

Screw terminals are the green blocks with screws on top: **3 on the relay**
(marked `COM`, `NO`, `NC`) and **2 on the ACS712** (the small blue board in your
photo, with the green block on its right-hand edge).

For every screw: loosen it, push the bare metal of the wire fully in, tighten
down onto the **metal, not the plastic**. Then tug the wire gently. If it moves,
it is not connected. **Loose screws are the number one reason this stage reads
`0.00A`.**

### Step D.1 — Free the battery wires
In your photo the holder's red and black wires end in a **black barrel plug**.
You do not need that plug — one 3.7 V cell cannot run an Uno anyway (that needs
two cells; see `BUILD_GUIDE.md` Part 13).

Either **unscrew the plug's plastic collar** if it is the screw-terminal kind and
pull the wires out, or **cut the plug off** and strip about 10 mm of insulation
off each wire.

Then, on the **black** wire only: twist the loose strands tightly together,
clockwise, into one stiff point. That is what will go into a breadboard hole.

### Step D.2 — Wire 1: battery red (+) → relay `COM`
Battery **red** wire into the relay's **`COM`** screw. Tighten. Tug it.

`COM` is the middle screw of the three on most relay boards, but go by the
printed label, not the position.

### Step D.3 — Wire 2: relay `NO` → ACS712 screw 1
Take a **male-to-male jumper** (the coloured ones in your photo). Put one end in
the relay's **`NO`** screw and the other in **either** of the ACS712's two
screws. Tighten both.

`NO` means "normally open" — that gap is what the relay closes and opens. That is
the whole product in one wire.

### Step D.4 — Wire 3: ACS712 screw 2 → LOAD RAIL A
Another male-to-male jumper. One end in the ACS712's **other** screw. The other
end into **LOAD RAIL A, around column 60** — the same strip as your eleven
resistor legs, but far to the right of them so you can pull resistors without
knocking it out.

Which of the two ACS712 screws you used for which wire does not matter. The
firmware uses the size of the reading, not its direction.

### Step D.5 — Wire 4: LOAD RAIL B → battery black (−)
Push the twisted **black** battery wire directly into **LOAD RAIL B, around
column 60**. Straight down, firmly.

If it will not stay, twist the strands tighter, or tape the wire down to the
table so it is not pulling sideways on the hole.

### Step D.6 — Trace the ring with your finger
Say it out loud as you go:

> red → `COM` … `NO` → sensor … sensor → RAIL A … eleven resistors … RAIL B →
> black.

Four wires, eleven resistors, one closed ring. Nothing from this ring reaches the
Arduino's rails.

### Step D.7 — Last look at the Stage 1 pair
Check nothing you just did landed in the Stage 1 rails, and that no wire runs
between the two rail pairs.

---

# PART E — Run it

### Step E.1 — Upload the new firmware
**The numbers changed today** for your 110 Ω resistors. The old ones assumed
100 Ω and would have misread this demo.

1. Plug the USB back in. **Leave the cell out.**
2. Arduino IDE → open `Bringup/Bringup.ino` → upload.
3. **Tools → Serial Monitor**, and set the speed box at the bottom right to
   **9600**.

### Step E.2 — Read the startup report
You should see:

```
Calibrating sensor zero... done. resting value = 512
Button1 (D2): ok, released
Button2 (D3): ok, released
Load bank: 11 x 110 ohm = 0.37A
Demo: start with all 11 in, wait 1 min, then pull down to 4 and keep your hands off for 90 s.
  cuts at 5 or fewer; never go below 3 - at 2 it reads as unplugged.
[READY]  now 0.00A
```

The board is telling you the demo itself, worked out from its own constants.

**It must say `0.00A` with the cell out.** If it does not, type `z` and press
Enter to re-measure zero. If a reading still creeps back, one of your load wires
is touching the Arduino's rails.

### Step E.3 — Drop the cell in
Red is `+`. Put the 18650 into its holder.

Within a second or two:

```
>> load detected
[SETTLE]    now 0.37A  (~11 of 11 resistors)
```

and five seconds later:

```
>> charging
[CHARGING]  now 0.37A  (~11 of 11 resistors)   peak 0.37A   cut below 0.18A   running 6s
```

**`(~11 of 11 resistors)` is the number that matters.** The board is counting your
resistors from the current alone. If it says 11 and you built 11, the sensor and
the maths agree and the rest will work. If it says 8 or 14, stop and fix the
reading (table below).

The resistors will get warm. 0.12 W each in a ¼ W part. Normal.

### Step E.4 — Wait one full minute
The firmware refuses to cut off in the first 60 seconds. That guard is what stops
an already-full phone being cut the instant you plug it in.

### Step E.5 — Pull down to 4
Now pull out **seven** resistors — the **right-hand seven** — leaving the
**leftmost four** in place. Take them out one at a time and watch the count fall:

| Resistors left | Reads about | Serial says |
|---|---|---|
| 11 | 0.37 A | `~11 of 11` |
| 8 | 0.27 A | `~8 of 11` |
| 6 | 0.20 A | `~6 of 11` |
| **4** | **0.13 A** | `~4 of 11` |

`cut below` is **0.18 A**, so at four you are clearly under it and the clock
starts:

```
>> current dropped - starting 90s confirmation
[CHARGING]  now 0.13A  (~4 of 11 resistors) ... LOW for 12s of 90s
```

**Stop at 4. Never go below 3.** At two resistors (0.07 A) the reading is close
enough to zero that the socket decides you unplugged the device, and it goes
quietly back to `READY`. Not a fault — just the wrong answer, and it ends the run.

### Step E.6 — Hands off for 90 seconds
Do not touch the board. Every time the current pops back above 0.18 A the 90
seconds starts again — that is the guard that stops a momentary dip cutting a real
laptop off mid-charge.

Then:

```
****************************************
  FULL - POWER CUT
  cutoff #1
  press button2 to re-arm
****************************************
```

Three beeps, twice. The relay clicks. The current goes to zero and the resistors
go cold.

**That is the entire product working.**

### Step E.7 — Do it again
Tap **Button 2** to re-arm. Put all eleven resistors back. It will do the whole
thing again.

---

## If something is wrong

| What you see | What it means |
|---|---|
| `0.00A` with the cell in | The ring is open. Nine times out of ten it is a screw tightened onto insulation. Redo `COM`, `NO` and both ACS712 screws |
| Resistor count off by 2 or more | Sensor calibration. In `Bringup.ino` change `SENSOR_MV_PER_AMP`: reading too high → raise it (190, 195); too low → lower it (180, 175). Re-upload |
| `*** PEAK TOO LOW ***` | Fewer than about 8 resistors are actually conducting. It will cut at 60 s as a "trickle", which looks like a real cutoff but skips the taper. Reseat every leg |
| Never leaves `READY` | Under 0.12 A, so under four resistors' worth is getting through. Check the bank and the screws |
| Goes back to `READY` mid-run | You went below three resistors, or a leg fell out |
| A reading with the cell out | Type `z`. If it creeps back, a load wire is touching the Arduino's rails |
| Nothing happens after 90 s | Did the current stay under `cut below` the whole time? Any bounce upward restarts the clock |
| `!! OVERCURRENT` | The battery is shorted. **Take the cell out now**, then look for two legs touching across the rails |
| Cell gets hot | Same thing. Cell out immediately |

---

## Later: the rocker switch

Your rocker has **two spade blades, not three pins** — plain on/off, no middle
pin, either blade can be either side. The blades do not fit a breadboard, so it is
not worth fighting on the first run.

Once the cutoff works, put the switch between the battery and the relay:

```
battery +  ->  rocker blade 1
rocker blade 2  ->  relay COM
```

To land a wire on a blade: strip 15 mm, wrap it tightly around the blade, tape
over it.

The enclosure already has a 30 × 24 mm opening in the back wall and three
interchangeable bezel plates for this switch — `enclosure/README.md` section 5.

---

## What changed in the firmware today

Your resistors measured **110 Ω**, not the 100 Ω the original guide assumed. With
11 in parallel the load can only sit on multiples of 33.6 mA:

```
resistors in |  1    2    3    4    5    6    7    8    9   10   11
current (mA) | 34   67  101  134  168  202  235  269  302  336  370
```

One ADC count is 26 mA — most of a whole step. So a threshold sitting *on* a step
is a coin toss, and two of them were:

| Constant | Was | Now | Why |
|---|---|---|---|
| taper threshold | 39% of peak | 49% of peak | 39% put the cut 10 mA from the 4-resistor step; 49% sits midway between steps 5 and 6 |
| `UnplugMa` | 80 mA | 50 mA | 80 mA was 13 mA under the 3-resistor step — the demo's own end state was one count of drift from reading as "unplugged" |
| `TaperFloorMa` | 100 mA | 115 mA | 100 mA landed exactly on the 3-resistor step (101 mA) |
| `PlugDetectMa` | 150 mA | 120 mA | Between steps 3 and 4 instead of on step 5 |
| `MinSessionPeakMa` | 300 mA | 250 mA | A full bank is 370 mA nominal, but a low cell or a 15%-low calibration lands near 300 — and dropping under it silently switches to the trickle path |

Changed in both `Bringup/Bringup.ino` and `SmartSocket/src/core/Config.h` so the
two rigs behave identically. Core suite 109/109; `Bringup` compiles at 28% flash.

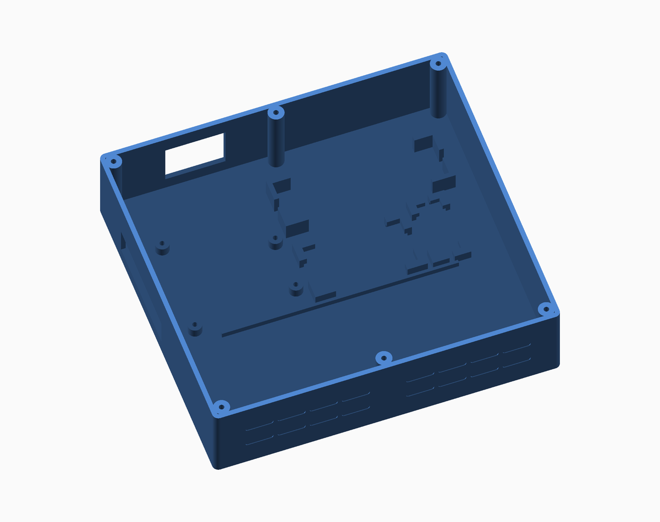
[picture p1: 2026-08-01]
enclosure/preview/03_base_inside.png

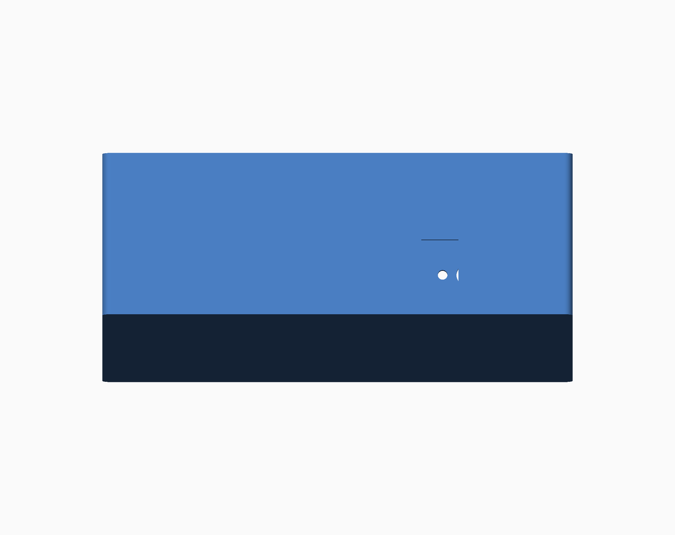
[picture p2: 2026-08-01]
enclosure/preview_slim/04_base_front_switch.png

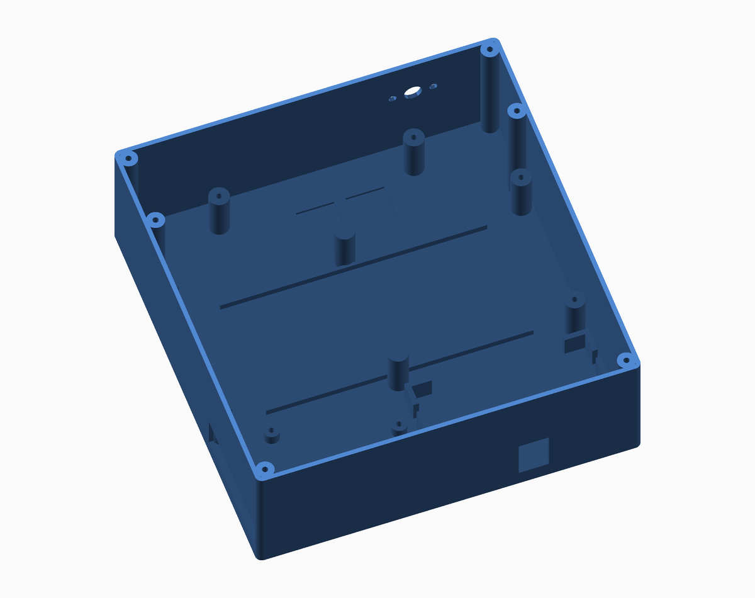
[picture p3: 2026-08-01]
enclosure/preview_slim/03_base_inside.png

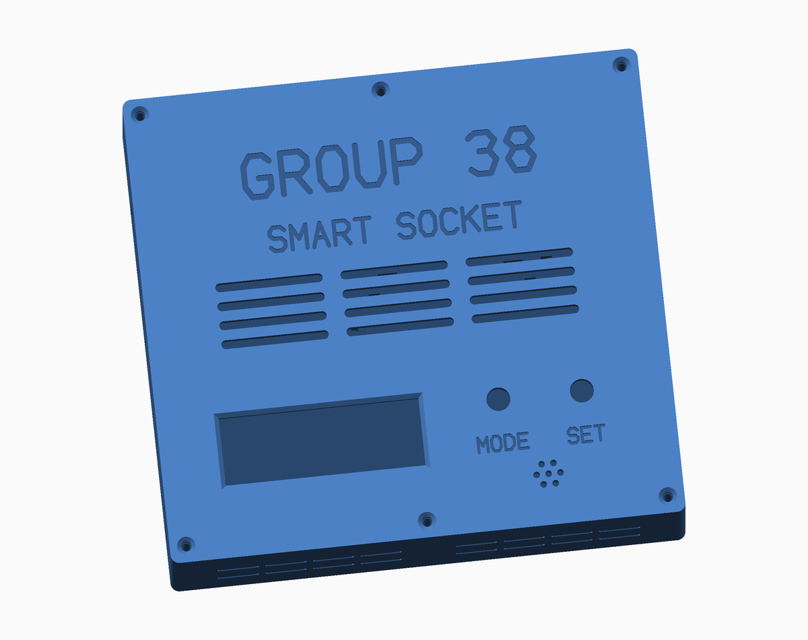
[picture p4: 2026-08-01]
enclosure/preview/02_lid_top.png

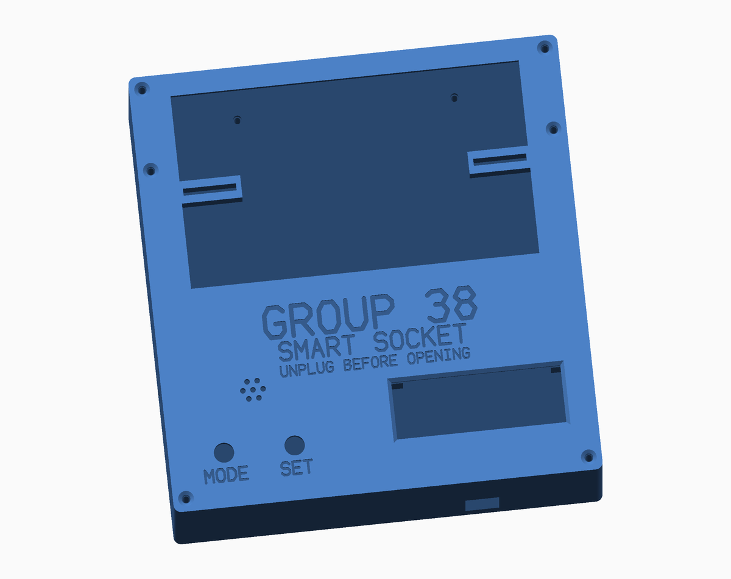
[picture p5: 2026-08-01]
enclosure/preview_slim/02_lid_top.png

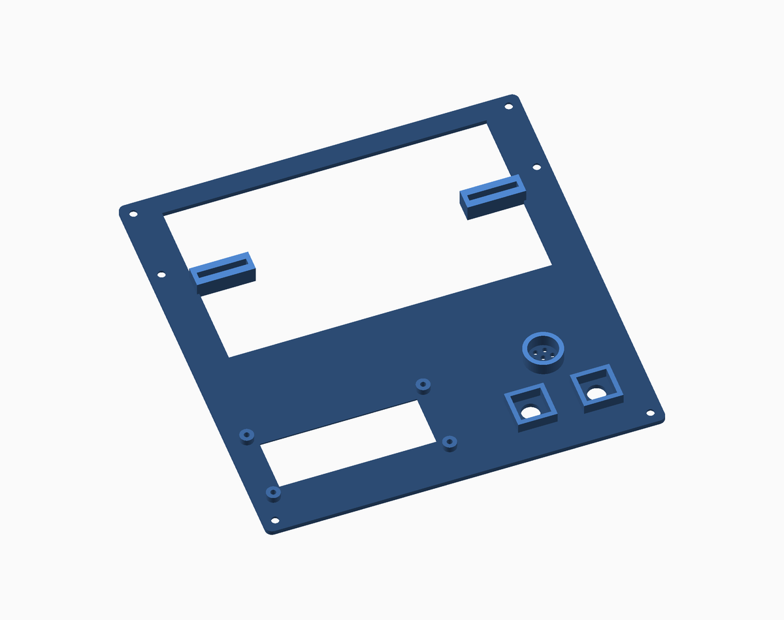
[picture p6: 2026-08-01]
enclosure/preview_slim/05_lid_underside.png

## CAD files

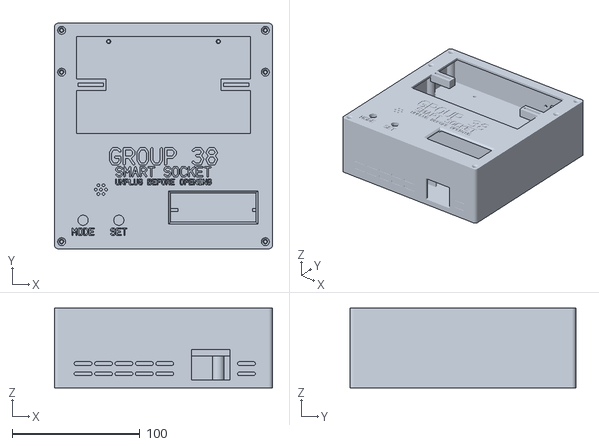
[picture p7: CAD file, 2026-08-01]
enclosure/stl/SmartSocket_Assembly.stl
170.8 x 176.8 x 62.4

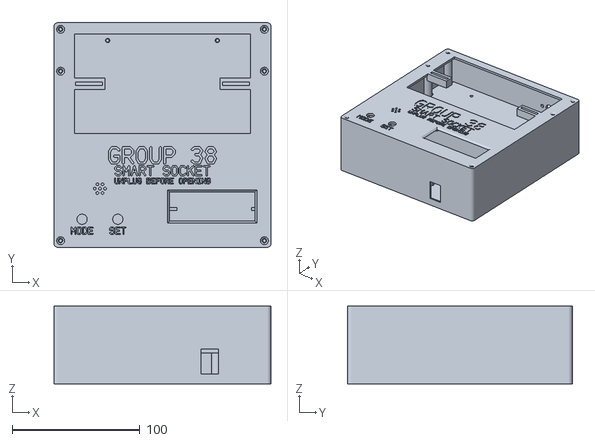
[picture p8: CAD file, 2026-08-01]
enclosure/stl_slim/SmartSocket_Assembly.stl
170.0 x 176.0 x 61.0

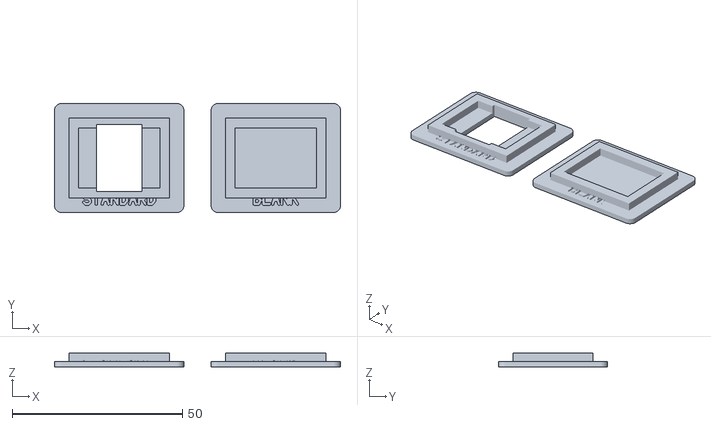
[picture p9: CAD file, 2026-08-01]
enclosure/stl/SmartSocket_SwitchPlates.stl
84.0 x 32.0 x 4.00

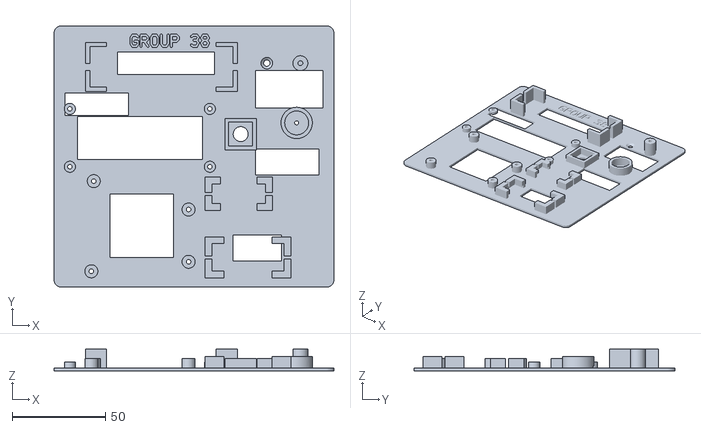
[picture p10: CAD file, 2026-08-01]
enclosure/stl_slim/SmartSocket_FitCheck.stl
150.0 x 140.0 x 11.6

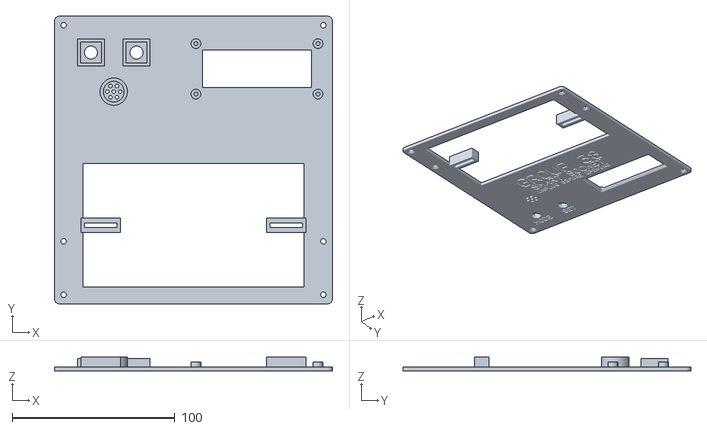
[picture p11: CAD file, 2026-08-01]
enclosure/stl/SmartSocket_Lid.stl
170.8 x 176.8 x 8.60

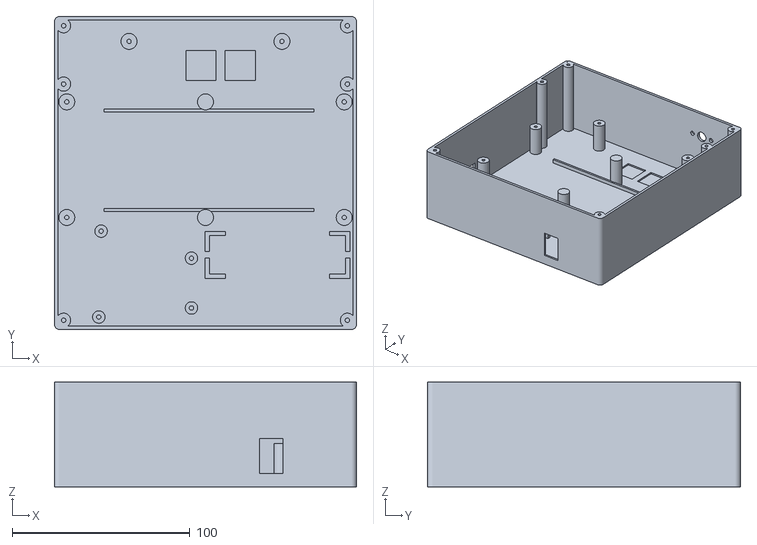
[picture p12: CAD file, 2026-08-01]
enclosure/stl_slim/SmartSocket_Base.stl
170.0 x 176.0 x 58.8

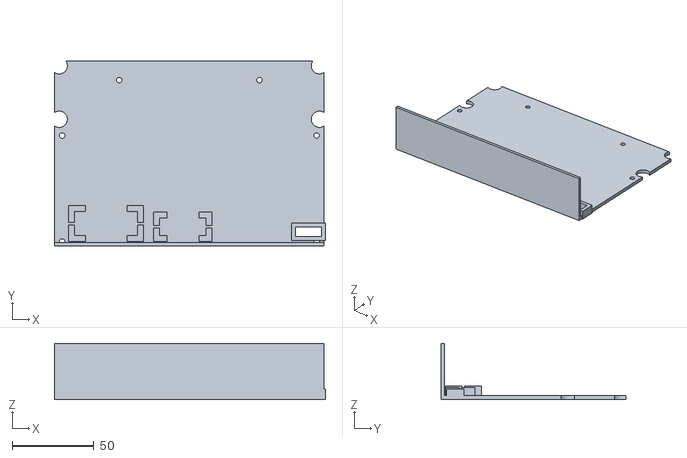
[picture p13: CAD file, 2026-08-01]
enclosure/stl_slim/SmartSocket_Shelf.stl
166.2 x 113.4 x 34.4

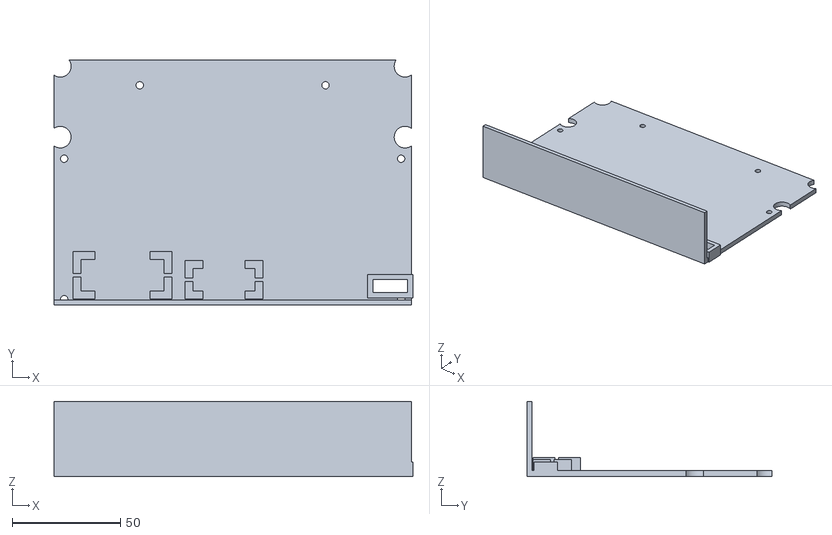
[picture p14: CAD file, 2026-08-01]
enclosure/stl/SmartSocket_Shelf.stl
166.2 x 113.4 x 34.8

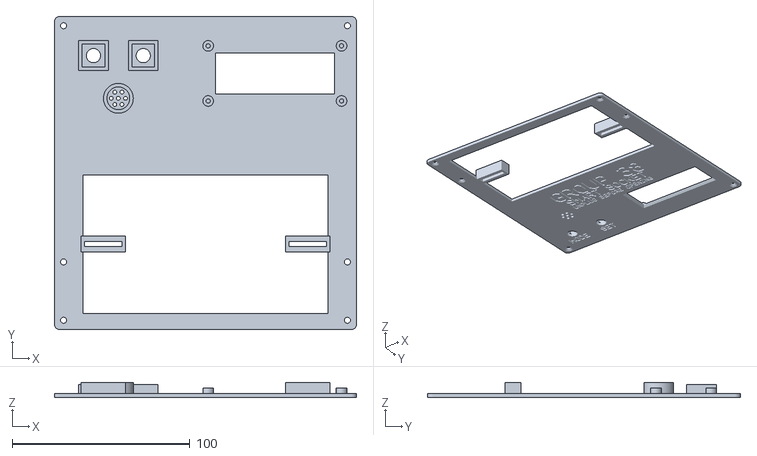
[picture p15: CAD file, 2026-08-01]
enclosure/stl_slim/SmartSocket_Lid.stl
170.0 x 176.0 x 8.20

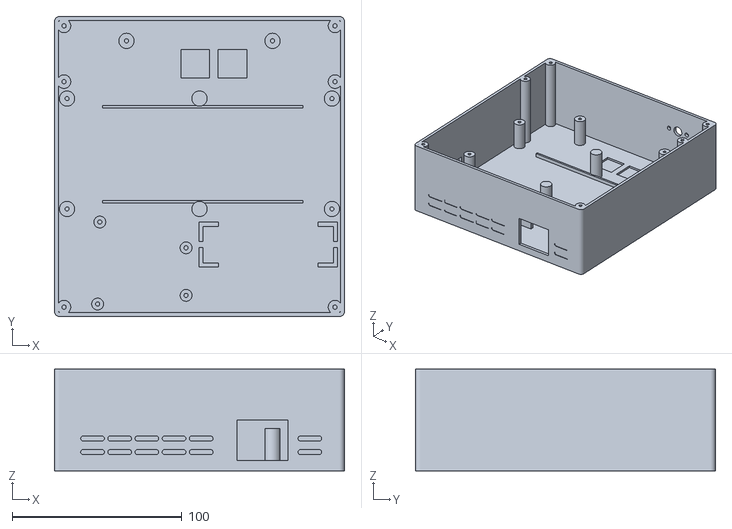
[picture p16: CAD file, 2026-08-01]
enclosure/stl/SmartSocket_Base.stl
170.8 x 176.8 x 59.8

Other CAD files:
enclosure/stl/SmartSocket_FitCheck.stl

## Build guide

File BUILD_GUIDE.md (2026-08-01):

# Build Guide — Smart Socket

Every step, in order, start to finish. Do them in order. Do not skip ahead.

**Everything here uses only the parts on your list. Nothing extra to buy. No mains. No
cutting. Nothing dangerous.**

---

# PART 0 — What you are building

Your parts list has a **Li-ion battery, a case, and an SPDT switch**. That battery pack is
your power source. It stands in for the wall.

| The idea | Your build |
|---|---|
| Wall power | Li-ion battery + SPDT switch |
| Plugged-in device | A load on the breadboard |
| Device charging (drawing power) | Load pulling current |
| Battery full (power drops) | You reduce the current |
| Cut the power | Relay opens |
| Show status + beep | LCD + buzzer |

The firmware is identical either way. It measures current, spots the drop, waits to be sure,
cuts the relay, beeps, and shows `FULL - POWER CUT`. The only difference is that a battery
supplies the current instead of a wall socket.

Highest voltage anywhere in this project: **3.7 volts**. It cannot hurt you.

---

# PART 1 — Parts checklist

All from your kit. Lay them out and tick them off.

| # | Part | What it looks like |
|---|---|---|
| 1 | Arduino Uno | Blue board, USB socket on one end |
| 2 | ACS712 current sensor (5A) | Small board, 2 green screw terminals one side, 3 pins the other |
| 3 | Relay module (1 channel) | Board with a blue box on it, 3 screw terminals, 3 pins |
| 4 | 16x2 I2C LCD | Screen with a small board soldered on the back, 4 pins |
| 5 | Tactile buttons x2 | Tiny square buttons, 4 legs |
| 6 | Active buzzer | Small black cylinder, 2 legs |
| 7 | Resistors — **about 11 of the same value**, 100Ω is ideal | See Part 9 |
| 8 | Breadboard | White block full of holes |
| 9 | Jumper wires | Male-to-male |
| 10 | Li-ion battery (18650) + holder | Blue cylinder in a plastic case with red and black wires |
| 11 | SPDT switch | The small black rocker switch |
| 12 | USB cable | Arduino to your PC |

The Arduino is powered from your PC over USB. The battery only powers the load.

---

# PART 2 — Set up the software

**Step 2.1** — Open Arduino IDE.

**Step 2.2** — **File** → **Open**.

**Step 2.3** — Go to:
```
C:\Users\kyere\Documents\codes\embedded systems\SmartSocket\SmartSocket.ino
```
Click it, click **Open**.

**Step 2.4** — **Tools** → **Board** → **Arduino AVR Boards** → **Arduino Uno**.

**Step 2.5** — Near the top of the code, find:
```cpp
#define SENSOR_MODE_AC 0
```
Check it says **`0`**. It is already set for you. Change nothing.

**Step 2.6** — Click the **tick** button (top left). Wait.

**Step 2.7** — At the bottom you should see `Sketch uses 11130 bytes`. It worked.

Orange or red errors? Go to Part 12.

---

# PART 3 — Your breadboard

- The **long rows** marked `+` and `−` are **power rails**. Every hole along one long row is
  joined together.
- In the **middle**, each **vertical column of 5 holes** is joined together.
- The **centre gap** separates left from right.

Two wires in the same 5-hole column are connected. In different columns, they are not.

---

# PART 4 — Power rails

**Keep the Arduino unplugged for Parts 4 to 7.**

**Step 4.1** — Unplug the Arduino. No lights on.

**Step 4.2** — Arduino **`5V`** → breadboard **`+` rail**.

**Step 4.3** — Arduino **`GND`** → breadboard **`−` rail**.

---

# PART 5 — LCD

The small board on the back of your LCD has 4 pins: `GND`, `VCC`, `SDA`, `SCL`.

**Step 5.1** — LCD `GND` → **`−` rail**

**Step 5.2** — LCD `VCC` → **`+` rail**

**Step 5.3** — LCD `SDA` → Arduino **`A4`**

**Step 5.4** — LCD `SCL` → Arduino **`A5`**

`A4` and `A5` only. No other pins work for this.

---

# PART 6 — Buttons, buzzer, relay

## Buttons

A tactile button's 4 legs are joined in pairs inside. **Always use two legs diagonally
opposite each other.** Two legs on the same side is a permanent short.

**Step 6.1** — Push button 1 into the breadboard **across the centre gap** — 2 legs each
side.

**Step 6.2** — Push button 2 in the same way, a few columns along.

**Step 6.3** — Button 1: one leg → Arduino **`D2`**

**Step 6.4** — Button 1: **diagonally opposite** leg → **`−` rail**

**Step 6.5** — Button 2: one leg → Arduino **`D3`**

**Step 6.6** — Button 2: **diagonally opposite** leg → **`−` rail**

Button 1 = **NEXT**. Button 2 = **ACTION**.

No resistors on the buttons.

## Buzzer

One leg is **longer**. The long leg is `+`.

**Step 6.7** — Put the buzzer in the breadboard.

**Step 6.8** — Put a **100Ω resistor** so one end shares a column with the buzzer's **long
leg**.

**Step 6.9** — Resistor's other end → Arduino **`D8`**

**Step 6.10** — Buzzer **short leg** → **`−` rail**

## Relay — pins only

**Step 6.11** — Relay `VCC` → **`+` rail**

**Step 6.12** — Relay `GND` → **`−` rail**

**Step 6.13** — Relay `IN` → Arduino **`D7`**

Leave the relay's 3 **screw terminals** empty for now.

---

# PART 7 — Current sensor

**Step 7.1** — ACS712 `VCC` → **`+` rail**

**Step 7.2** — ACS712 `GND` → **`−` rail**

**Step 7.3** — ACS712 `OUT` → Arduino **`A0`**

Leave the 2 **screw terminals** empty for now.

---

# PART 8 — Test everything before the load

**Step 8.1** — Check against this table:

| Arduino pin | Goes to |
|---|---|
| `5V` | `+` rail |
| `GND` | `−` rail |
| `A0` | ACS712 `OUT` |
| `A4` | LCD `SDA` |
| `A5` | LCD `SCL` |
| `D2` | Button 1 |
| `D3` | Button 2 |
| `D7` | Relay `IN` |
| `D8` | 100Ω resistor → buzzer long leg |

| `+` rail | `−` rail |
|---|---|
| LCD `VCC` | LCD `GND` |
| Relay `VCC` | Relay `GND` |
| ACS712 `VCC` | ACS712 `GND` |
| | Button 1 diagonal leg |
| | Button 2 diagonal leg |
| | Buzzer short leg |

**Step 8.2** — Plug the Arduino into your PC.

**Step 8.3** — **Tools** → **Port** → select the COM port. Unsure which? Unplug the Arduino,
look at the list, plug it back in, pick the one that reappeared.

**Step 8.4** — Click the **arrow** button to upload. Wait for `Done uploading`.

**Step 8.5** — The LCD shows:
```
Smart Socket
Calibrating...
```
then:
```
READY      0.00A
00:00:00  pk0.00
```

**Step 8.6** — You hear the relay **click** once at startup.

**Step 8.7** — Press **Button 1 (NEXT)**. Screen changes to `Cut at / Taper`. Press again
for `Cutoffs / Saved`. Press again to return.

**Step 8.8** — Hold **Button 2 (ACTION)** for 2 seconds. Screen shows `MANUAL POWER OFF`,
relay clicks.

**Step 8.9** — Hold Button 2 again for 2 seconds. Back to `READY`, relay clicks.

### Blank LCD?

1. Turn the small **blue screw** on the LCD's back board slowly. That is the contrast.
2. Still nothing? Open `SmartSocket\src\core\Config.h`, change `LcdI2cAddress = 0x27` to
   `0x3F`, upload again.

**Everything in Part 8 must work before Part 9.**

---

# PART 9 — Build the load

> **Follow `docs/STAGE2.md` instead of this part.** It was written against the
> resistors as actually measured — **110 Ω, not 100 Ω** — and it returns the load
> straight to the battery rather than through the Arduino's `−` rail. Both matter.
> Parts 1–8 below are still correct; this part and Part 10 are kept for the
> reasoning only.

## Why 11 resistors

Your ACS712 is the **5A** model. It cannot see small currents — anything under about
**0.06A** is lost in its own noise. Your load must pull at least **0.35A** or the sensor is
blind to it.

One 18650 gives **3.7V**. Ohm's law:

- One 100Ω resistor across 3.7V = **0.037A**. Far too small to see.
- Put **10 of them side by side (in parallel)** = **0.37A**. The sensor sees that clearly.

Each resistor still only handles 0.037A and stays cool. Ten together add up to a load the
sensor can measure. (The 11th resistor is the one already on your buzzer.)

**If you don't have ten 100Ω resistors:** any value from 100Ω to 220Ω works. Just use more
of them for higher values — about 10 for 100Ω, 15 for 150Ω, 22 for 220Ω. Do not use
anything below 100Ω; it will get hot.

## Build the resistor bank

**Step 9.1** — Unplug the Arduino.

**Step 9.2** — Pick two empty columns on the breadboard, a few holes apart. Call them
**column A** and **column B**.

**Step 9.3** — Push a resistor in so **one leg is in column A and the other is in column B**.

**Step 9.4** — Do that **nine more times**. Ten resistors, all side by side, every one
bridging column A to column B.

They should look like a row of little fences. All ten are now in parallel.

## Wire the battery circuit

**Step 9.5** — Put the 18650 in its holder. **Red wire is `+`. Black wire is `−`.**

**Step 9.6** — Battery **red (+)** → **one blade** of the rocker switch. The switch in
this kit has **two spade blades, not three pins** — there is no middle pin, and either
blade can be either side. The blades do not fit a breadboard; strip 15 mm of a jumper,
wrap it round the blade and tape it. Or leave the switch out of the first run entirely
and use the cell as the on/off, which is what `docs/STAGE2.md` does.

**Step 9.7** — **The other blade** of the rocker switch → **relay screw terminal `COM`**.
Tighten.

**Step 9.8** — Jumper wire from **relay `NO`** → **ACS712 screw terminal 1**. Tighten.

**Step 9.9** — Jumper wire from **ACS712 screw terminal 2** → **column A** on the
breadboard.

**Step 9.10** — Jumper wire from **column B** → **battery black (−)**, directly.

**Step 9.11** — **Not** through the breadboard `−` rail. The ACS712's screw terminals are
isolated from its `VCC`/`GND` pins, so the load needs no shared ground with the Uno —
and keeping 0.37 A out of the Arduino's ground rail removes the voltage shift that
showed up earlier in this build as a phantom 0.10–0.12 A reading.

The current path is now:
```
battery + → switch → relay → ACS712 → resistor bank → battery −
```

**Step 9.12** — Set the SPDT switch to **OFF**.

---

# PART 10 — Run the demo

**Step 10.1** — Switch the SPDT switch **OFF**.

**Step 10.2** — Plug the Arduino into your PC.

**Step 10.3** — Wait for `READY   0.00A`. It must read **0.00A** — nothing is flowing yet.

**Step 10.4** — Now flick the SPDT switch **ON**.

**Step 10.5** — You hear **one short beep**. The LCD shows:
```
SETTLE     0.37A
```
and after 5 seconds:
```
CHARGING   0.37A
00:00:03  pk0.37
```

**Your "device" is now charging.** The resistors may feel slightly warm. That is normal.

**Step 10.6** — Press **Button 1 (NEXT)** to see the Detail screen:
```
Cut at     0.14A
Taper 30%    n=0
```
That `Cut at` number is the level the socket will cut off below. It worked it out from your
load by itself.

**Step 10.7** — Press Button 1 again to return to the Status screen.

## Simulate the battery filling up

**Step 10.8** — Wait **at least 1 minute** with all ten resistors in. The socket will not cut
off before then, on purpose.

**Step 10.9** — Now **pull out resistors one at a time.** Watch the current drop on the LCD:

| Resistors left | LCD shows about |
|---|---|
| 10 | 0.37A |
| 8 | 0.30A |
| 6 | 0.22A |
| 4 | 0.15A |
| **3** | **0.11A** |

**Step 10.10** — Stop at **3 resistors**. The LCD reads about `0.11A`, which is below the
`Cut at` figure.

**Do not pull out more than 3.** Below about 0.08A the socket decides the device has been
unplugged and just goes back to `READY`.

**Step 10.11** — Leave it alone for **90 seconds**. Do not touch anything.

**Step 10.12** — You hear **three beeps, twice**, the relay clicks, and the LCD shows:
```
FULL - POWER CUT
Press ACTION
```

**The project works.** The relay has cut the power. The resistors are cold. Current is zero.

**Step 10.13** — Press **Button 1 (NEXT)** twice to see the Stats screen:
```
Cutoffs        1
Saved     0h01m
```

**Step 10.14** — Press **Button 2 (ACTION)** once to re-arm. Back to `READY`.

## What just happened

1. Current was high → `CHARGING`
2. You dropped the current → the socket saw it
3. It waited 90 seconds to be sure it was not a glitch
4. It cut the relay and beeped → `FULL - POWER CUT`
5. It remembered the cutoff in its EEPROM — the count survives unplugging

That is the whole product.

## Do it again

**Step 10.15** — Put all ten resistors back. Switch the SPDT switch OFF, then ON.

**Step 10.16** — Repeat. On the Detail screen you will see `Taper` change slightly each
time. That is the adaptive learning — it is tuning itself to your load.

---

# PART 11 — Checking the readings

**Step 11.1** — With all 10 resistors in and the switch ON, the LCD should read about
`0.37A`.

**Step 11.2** — If it is consistently off, open `SmartSocket\src\core\Config.h`:
```cpp
const int32_t SensorMvPerAmp = 185;
```
- Reads **too high** → raise it (190, 195)
- Reads **too low** → lower it (180, 175)

Upload again after each change.

**Step 11.3** — If it shows current with the switch OFF: switch off, unplug the Arduino,
plug it back in. It measures its own zero point every time it starts.

---

# PART 12 — Troubleshooting

| Problem | Do this |
|---|---|
| Compile error mentions `LiquidCrystal_I2C` | **Tools** → **Manage Libraries** → search `LiquidCrystal I2C` → install the one by **Frank de Brabander** |
| Upload fails, port not found | **Tools** → **Port** → pick the COM port. Unplug/replug to see which appears |
| LCD backlit but no text | Turn the blue screw on the LCD's back board |
| LCD dead | Check `VCC`/`GND`. Then change `LcdI2cAddress` to `0x3F` in `Config.h` |
| Relay clicks backwards | `SmartSocket\src\hal\HalPins.h`, change `RelayActiveLow = true` to `false` |
| Buttons dead | You used two legs on the same side. Use **diagonally opposite** legs |
| Buzzer silent or always on | Legs are backwards. Long leg → resistor, short leg → `−` rail |
| Never leaves `READY` when switch is ON | Load too small. Add more resistors. You need at least 0.35A |
| Resistors hot | Your resistors are below 100Ω. Use 100Ω or higher |
| Goes to `READY` instead of `FULL` | You pulled out too many resistors. Leave 3 in |
| Cuts off too early | `Config.h`, change `TaperConfirmMs` from `90000` to `180000` |
| Never cuts off | Did you wait a full 90 seconds without touching it? Is the current below the `Cut at` figure? |
| `! OVERCURRENT !` | Short circuit. Switch off. Check the battery is not wired straight across |
| Current reads 0.00A with switch ON | Check the SPDT middle pin, the relay `COM`/`NO` screws, and both ACS712 screws |

---

# PART 13 — Optional: run the Arduino from the battery too

Only if you want it running with no PC.

One 18650 is **3.7V** — **not enough** to power an Arduino Uno. You need **two cells in
series** (7.4V) in a 2-cell holder. If you only have one cell, skip this part and keep the
USB cable plugged in. That is perfectly fine.

With two cells:

**Step 13.1** — Battery **red (+)** → middle pin of the SPDT switch

**Step 13.2** — One outer pin of the switch → Arduino **`VIN`**

**Step 13.3** — Battery **black (−)** → Arduino **`GND`**

**Never connect the battery and the USB cable at the same time.**

---

# Quick reference

## Control side (breadboard, 5V from Arduino)

| Arduino pin | Connects to |
|---|---|
| `5V` | `+` rail |
| `GND` | `−` rail |
| `A0` | ACS712 `OUT` |
| `A4` | LCD `SDA` |
| `A5` | LCD `SCL` |
| `D2` | Button 1 (NEXT) |
| `D3` | Button 2 (ACTION) |
| `D7` | Relay `IN` |
| `D8` | 100Ω resistor → buzzer long leg |

| `+` rail | `−` rail |
|---|---|
| LCD `VCC` | LCD `GND` |
| Relay `VCC` | Relay `GND` |
| ACS712 `VCC` | ACS712 `GND` |
| | Button 1 diagonal leg |
| | Button 2 diagonal leg |
| | Buzzer short leg |
| | Battery black (−) |
| | Resistor bank column B |

## Load side (3.7V battery)

```
battery + → rocker blade 1        (2 blades, no middle pin - or omit for the first run)
rocker blade 2 → relay COM
relay NO → ACS712 terminal 1
ACS712 terminal 2 → resistor bank (node A)
resistor bank (node B) → battery −     NOT the − rail
```

This loop never touches the Arduino's rails. See `docs/STAGE2.md`.

## The demo

1. All **11** resistors in, power ON → `CHARGING 0.37A`
2. Wait 1 minute
3. Pull resistors out until **4** remain → about `0.13A` (cut-below is `0.18A`)
4. Wait 90 seconds, hands off
5. Three beeps → `FULL - POWER CUT`
6. Tap **ACTION** to re-arm

Never go below 3 resistors — at 2 the socket reads it as unplugged and returns to
`READY`.

## Buttons

- **Button 1 (NEXT)** — change screen
- **Button 2 (ACTION)** — tap to reset after cutoff; hold 2s to force power off/on

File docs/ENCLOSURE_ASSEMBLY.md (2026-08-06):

# Fitting the build into the enclosure

You have the three printed parts. This is the order to put everything into them,
and the two places where the printed geometry does not match what the wiring
needs.

This continues from `docs/FINAL_BUILD.md`. That document gets you a working
socket lying on the bench; this one gets it into the box. **Everything in
`FINAL_BUILD.md` STEPS 1–45 must already work before you start here.** Boxing a
build that has never run means every fault you meet afterwards has two possible
causes.

Where the two documents disagree, this one is right — see "Corrections to
FINAL_BUILD" at the end.

---

## Orientation — read this first, everything below depends on it

Put the **base** on the bench, open side up, and turn it so the **rectangular
switch cutout is on the wall nearest you**.

That is now fixed for the rest of the document:

| Wall | How you know it | What goes through it |
|---|---|---|
| **FRONT** (nearest you) | 13.4 × 19.6 mm rectangular cutout, low down | Rocker switch |
| **LEFT** | one wide slot, ~15 mm tall, near the front corner | Arduino USB — **5 V only** |
| **BACK** | round 8 mm hole high up, with two small holes either side | Mains cord, 230 V |
| **RIGHT** | plain, apart from vent slots | nothing |

Inside you are looking at:

- **Front zone** — the full-height open area along the front wall, about 58 mm
  deep. Four short posts for the Arduino, and a rectangle of four L-brackets to
  their right (the 18650 bay, unused).
- **Eight round posts**, 22 mm tall, filling the rest of the box. The shelf
  lands on these.
- **Six tall pillars** up the left and right edges, running floor to rim. Those
  are the lid screw bosses — do not confuse them with the shelf posts. Shelf
  posts stop at 22 mm; bosses go all the way up.

The **shelf** has a 2 mm wall standing up along one long edge. **That wall faces
the front.** It is the barrier between 230 V and everything else.

The **lid**, seen from the underside, has: a large rectangular opening with two
small bridging tabs (the socket), a smaller rectangular window with four 6 mm
bosses around it (the LCD), two square collars and one round collar with a ring
of small holes (buttons and buzzer).

---

## The zones, and why they matter

| Zone | Height above the floor | Contents | Voltage |
|---|---|---|---|
| Front zone | 0 – 56 mm, full height | Arduino; LCD, buttons, buzzer on the lid above | 5 V |
| Lower deck | 0 – 22 mm, under the shelf | Breadboard | 5 V |
| Mains deck | 24 – 56 mm, on the shelf | Socket, relay, ACS712 | **230 V** |

One route crosses between them: the raised collar with a 16 × 6 mm slot near the
back right of the shelf. Six wires go through it — relay `VCC`/`GND`/`IN` and
ACS712 `VCC`/`GND`/`OUT` — and nothing else.

---

## Buy list

**Screws.** All M3, all self-tapping into printed pilot holes. Ordinary M3
machine screws cut their own thread in PLA.

| Where | Count | Type |
|---|---|---|
| Lid to base | 6 | **M3 × 16 countersunk** |
| Shelf to posts | 6 | M3 × 12 pan |
| Arduino to standoffs | 4 | M3 × 8 pan |
| LCD to lid bosses | 4 | M3 × 6 pan |

An 8/12/16/20 mm M3 self-tapper assortment covers all of it except the
countersunk six.

**Also.** Hot glue gun · a soldering iron (six joints, no way round it) ·
**about 300 mm of 6 mm sleeving or heat-shrink** for STEP 8 · six small cable
ties · a chocolate-block connector strip · a multimeter · an 8 mm drill bit or a
round file.

---

# PART A — Before anything goes in

### STEP 0 — Lengthen the wires, before you touch the box

The bench build has everything within arm's reach of everything else. The boxed
build does not: the lid becomes a separate object carrying the socket, the LCD,
both buttons and the buzzer, joined to the base by twelve wires. If those wires
are short you will be working on live-capable terminals with the lid held up in
one hand.

Cut and make these up **first**, on the bench, before anything goes into the
enclosure.

| Wires | Count | Length | Note |
|---|---|---|---|
| LCD `VCC` `GND` `SDA` `SCL` | 4 | **250 mm** | female to the backpack, male to the board |
| Button MODE, button SET | 4 | **250 mm** | soldered to the legs, STEP 18 |
| Buzzer | 2 | **250 mm** | soldered, STEP 18 |
| ACS712 out → socket `L` | 1 | **250 mm** | mains |
| Neutral block → socket `N` | 1 | **250 mm** | mains |
| Relay + ACS712 signals | 6 | **150 mm** | these cross the shelf, not the lid |
| Cord `L` → rocker, rocker → relay `COM` | 2 | **250 mm** | mains, **sleeved**, STEP 8 |

250 mm is what lets the lid lie flat on the bench beside the base with nothing
under tension. That is the position you will do all the fault-finding in.

### STEP 1 — Deburr and dry-fit

Clip off any brim or stringing. Run a knife round the inside of every pilot hole
and the socket opening.

Check three fits, with nothing wired:

1. **Lid onto base.** It should drop on with the six countersunk holes centred
   over the six pillars. If it rocks, a corner has lifted during printing — sand
   the base rim flat.
2. **Shelf onto its posts, wall to the front.** The four large holes near its
   corners should drop over the four tall lid bosses; the six small holes should
   land on six of the eight posts. The two posts at the middle of the box get no
   screw — they are plain support.
3. **Socket faceplate into the lid, from the OUTSIDE.** The body drops through
   the big opening; the plate lands on the 4 mm rim. Its two fixing screws should
   line up somewhere along the two slotted tabs.

### The two tabs across the socket opening

Two 9 mm bridges span the opening, standing 6 mm proud of the lid's inner face,
each with a 2.8 mm slot through it. **They are the socket's fixing points.** The
plate's screws sit about 60 mm either side of centre, which lands them in the
middle of a 138 mm hole with nothing to bite; the tabs put plastic back exactly
there. The slot is a slot and not a hole so that any fixing centre from 90 to
150 mm works — the screw taps its own thread wherever it lands.

**If the socket will not seat, check the side you are fitting from first.** The
plate is 146 × 86 mm and the opening is 138 × 78 mm, so it cannot pass through
from the inside. It goes in from the **outer** face, body first.

Fitted the right way round, the two slots should line up with the two brass
fixing bosses on the back of the plate. If they do, the geometry is correct and
anything still stopping it is height, not position.

**If it still will not seat from the outside**, the brass boss tubes on the back
of the plate are landing on the tabs, which stand 6 mm proud of the inner face.
This is an anticipated failure, not a scrapped lid:

1. Sit the socket in from the outside and measure the gap between plate and lid.
   That is how much tab has to go — 6 mm is the whole projection.
2. Side cutters, then a flat file, until the stumps are **flush with the lid's
   inner face.** Do not cut into the lid itself; keep the 2.2 mm of lid
   thickness with the slot still running through it.
3. You have lost most of the thread depth, so do not rely on self-tapping. The
   socket's screws go through the plate lugs, through the slot, and onto a
   **washer and nut on the inside.** If the plate's own screws are too short to
   come through, use M3 × 20.

**Screws and nuts, not glue.** Pulling a plug out of a socket applies real force,
and a glued plate comes out with the plug eventually.

### STEP 2 — Prove the electronics one more time

With everything still on the bench as `FINAL_BUILD.md` left it, power the
Arduino from USB and confirm all five: boot chirp, `READY 0.00A`, relay clicks
closed, Button 1 cycles screens, Button 2 held 2 s cuts power.

Then **unplug the Arduino and unplug the mains lead from the wall.** They stay
unplugged until PART E.

### STEP 3 — Take the lid parts off the breadboard

Pull **both buttons** and the **buzzer** out of the breadboard. They are moving
to the lid.

**Leave the 110 Ω resistor where it is** — column 8 to column 12, lower block.
The buzzer comes back to **column 8**, on the far side of that resistor.

---

# PART B — The base

### STEP 4 — Rocker into the front wall

The switch has its own snap clips and the wall is recessed to 1.5 mm behind the
cutout so they grip. Push it in **from the outside** until both clips click.

Mount it **portrait** — taller than wide — so the moulded **O** is at the bottom
and **I** at the top.

Add a dab of hot glue on the inside afterwards. A switch that pushes back
through under thumb pressure would leave a live blade loose in the box.

### STEP 5 — Arduino onto its standoffs

Four 5 mm standoffs in the front zone, on the left. The hole pattern is
asymmetric and only fits one way: **the connector edge faces the LEFT wall.**

Sight through the left-wall slot before you screw down — you should see the USB
socket and the barrel jack looking straight out of it. If you see the far edge of
the board instead, turn it 180°.

Four M3 × 8 pan screws, finger tight plus a nudge. Do not crank them; you are
cutting thread in PLA 2.4 mm thick.

*Three of four holes lining up is normal on clone boards. Use three.*

### STEP 6 — Breadboard onto the lower deck

Two low ribs run across the floor behind the front zone. They set the
breadboard's depth; the side walls set its width.

Peel the adhesive backing and press it down between the ribs, **numbers reading
normally, column 0 to the left.** Once it is stuck it does not come up cleanly,
so line it up dry first.

### STEP 7 — Rewire the lower deck, now, before the shelf goes on

Once the shelf is screwed down you cannot reach under it. Rebuild the breadboard
exactly as `FINAL_BUILD.md` PART 3 and PART 4 describe, with three changes:

- **No buttons and no buzzer on the board.** Their wires arrive later from the
  lid.
- The **six module wires** (relay `VCC`/`GND`/`IN`, ACS712 `VCC`/`GND`/`OUT`) go
  in at the breadboard end now, with the far ends loose and **at least 150 mm**
  spare. They get threaded up through the shelf in STEP 11.
- The **ten lid wires** (LCD 4, buttons 4, buzzer 2) go in at the breadboard and
  Arduino end now, loose ends up, **250 mm** spare each.

Check against this before you go on:

| Uno pin | Goes to | Fitted now? |
|---|---|---|
| `5V` | `+` rail | yes |
| `GND` | `−` rail | yes |
| `A0` | ACS712 `OUT` | long tail, loose |
| `A4` | LCD `SDA` | long tail, loose |
| `A5` | LCD `SCL` | long tail, loose |
| `D2` | Button 1 | long tail, loose |
| `D3` | Button 2 | long tail, loose |
| `D7` | Relay `IN` | long tail, loose |
| `D8` | column 12, lower | yes |

and on the board: buzzer chain is `D8` → col 12 → **110 Ω** → col 8 → *(loose
tail up to the lid buzzer)*, and the buzzer's return tail goes to the `−` rail.

Route every loose tail toward the **front** of the box. Nothing should lie where
the shelf posts are.

---

# PART C — The barrier, and the one modification you have to make

### STEP 8 — Cut the mains crossing for the rocker

**Read this whole step before you drill.**

The mains cord enters the back wall, above the shelf. The rocker is in the front
wall, below it. There is no route between them: the shelf's partition seals the
mains compartment at the front, and the only hole in the barrier is the six-wire
pass-slot, which mains must not use. The printed parts have no path for the two
wires the rocker needs.

**Take the shelf out of the box and lay it on the bench.**

Drill an **8 mm hole through the upstanding partition wall**, positioned:

- **110 mm from the end of the shelf that will sit against the left wall**
  (the shelf is 166 mm long, so this is right of centre)
- **20 mm up from the top face of the shelf plate**

That spot is clear on both sides: on the mains side the relay ends at 52 mm, the
ACS712 at 94 mm and the pass-slot collar starts at 145 mm; on the front-zone
side the LCD's rear edge stops 10 mm short of the partition.

Deburr both faces. **Fit a grommet if you have one**; if not, line the hole with
a 15 mm length of sleeving glued in place. Bare PLA edges and mains insulation
should not be left to rub.

**The two rocker wires must be sleeved for their whole run inside the box.**
6 mm heat-shrink or PVC sleeving over the pair, from the hole to the switch. That
sleeve is the second layer of insulation that replaces the compartment wall you
just breached.

**What this costs.** The design's rule is that 230 V never leaves the mains deck.
This breaks it for two wires. In exchange they are sleeved, they hug the right
wall, they stay 80 mm from the Arduino, they never cross the lower deck and they
never pass over the breadboard. That is how a mains flex crosses a low-voltage
area in a commercial appliance, and it is the only option that does not mean
reprinting.

**If you will not accept mains in the low-voltage zone:** leave the rocker out,
blank the front cutout with a printed plug or a strip of PLA and hot glue, and
use the wall socket's own switch as the isolator. You lose the local isolator, so
"unplug from the wall before opening" becomes the only rule protecting you —
which is exactly what the lid already says.

### STEP 9 — Relay and ACS712 onto the shelf

Both clip into L-brackets on the shelf's top face, in the strip in front of where
the socket will sit. Brackets with a **lip** hold the board down; push one corner
under the lip and press the opposite corner in.

- **Relay** — the larger pocket, on the **left**. Its three screw terminals
  should face **forward**, toward the partition, so a screwdriver reaches them
  with the lid off.
- **ACS712** — the smaller pocket to its right, long axis running front-to-back.
  Its two screw terminals face forward for the same reason.

Leave all five screw terminals empty for now.

### STEP 10 — Six wires down through the pass-slot

Connect the six signal wires to the two modules' header pins:

| Module pin | Colour convention |
|---|---|
| Relay `VCC`, ACS712 `VCC` | red |
| Relay `GND`, ACS712 `GND` | black |
| Relay `IN`, ACS712 `OUT` | anything else |

Feed all six free ends **down** through the raised collar's slot, near the back
right of the shelf. Leave a loop of slack on the shelf side so the modules can be
lifted out later without pulling anything.

### STEP 11 — Shelf down

Lower the shelf onto its eight posts, **partition wall to the front**, guiding
the six wires down through the slot as it goes and keeping every low-voltage tail
from PART B clear of the underside.

The four large holes clear the tall lid bosses. Six M3 × 12 pan screws into the
six posts that have holes above them. The two middle posts get nothing.

**Do not overtighten.** These six screws carry the whole mains deck; a stripped
post cannot be re-cut.

Now join the six wires to the breadboard and Arduino, per the table in STEP 7.

---

# PART D — Mains

Plug out of the wall. Arduino unplugged. Rocker off.

### STEP 12 — Cord in, strain relief on

Feed the mains cord in through the round hole in the **back wall**, above the
shelf. Bring in **150 mm** of cord — enough to reach the far end of the deck.

Thread a cable tie through the two small holes beside the entry, round the cord,
and cinch it hard. **Pull the cord from outside.** If it moves at all, tighten
again. That tie is the only thing standing between a tug on the lead and a screw
terminal.

Identify **LIVE** before you go further — `FINAL_BUILD.md` STEP 27. It is the
core landing on the plug's right-hand pin with the plug face toward you and the
earth pin up. Mark it.

### STEP 13 — The chain

Five joints, in this order. Every one goes into a screw terminal or a
chocolate-block, onto bare copper, never onto insulation.

```
cord LIVE  ──┐
             │  (sleeved pair, through the STEP 8 hole,
             │   down the RIGHT wall, along the FRONT wall)
             └──►  rocker blade 1
                   rocker blade 2  ──►  back up through the same hole
                                        │
                                        ▼
                                   relay COM
                                   relay NO   ──►  ACS712 screw 1
                                                   ACS712 screw 2  ──►  ┐
                                                                        │
cord NEUTRAL ──► chocolate block ──────────────────────────────────────►│
                                                                        ▼
                                                             flying leads to the
                                                             socket in the lid
```

Working notes:

- **Rocker blades do not take a screw.** Strip 15 mm, wrap tight round the blade,
  heat-shrink over it. A spade crimp is better. Either blade either side.
- **Relay `NO`, never `NC`.** `NC` is live whenever the Arduino is not driving
  the relay, which includes every crash and every unplugged USB lead. `NO` fails
  to power-off. Leave `NC` empty.
- **Either ACS712 screw can be either side.** The firmware uses the size of the
  reading, not its direction.
- **Route the sleeved rocker pair round the walls**, not across the middle: out
  of the hole, right to the right-hand wall, down to the floor, forward along the
  right wall, then left along the front wall to the switch. Cable-tie it at three
  points. It must not lie on the battery bay, the Arduino, or any lid wire.

### STEP 14 — Two flying leads up to the lid

The socket lives in the lid, so the last two mains connections cross the hinge
line that this box does not have.

| From | To | Length |
|---|---|---|
| ACS712 screw 2 | socket **LIVE** | **250 mm** |
| Neutral block | socket **NEUTRAL** | **250 mm** |

250 mm lets the lid lie flat on the bench beside the base with nothing under
tension. Anything shorter and you will be working on live-capable terminals held
up in one hand.

Socket **EARTH** stays empty. Write `NO EARTH — CLASS II ONLY` on the plate.

**Dress both leads forward, into the strip in front of the socket.** The socket
body is 30 mm deep in a 32 mm compartment — there is no room under it.

### STEP 15 — Tug test

Pull every one of the five joints plus the two flying leads. Anything that moves
is not connected. A loose screw here is the number one cause of `0.00 A` later.

Trace the chain with a finger, out loud, once.

---

# PART E — The lid

### STEP 16 — LCD

Four M3 × 6 pan screws into the four 6 mm bosses around the window. The display
faces out through the window; the backpack, with its blue contrast screw, faces
into the box.

The window is cut to the **active display area**, not the metal bezel, so the
bezel overlaps the opening on all sides. That is correct.

### STEP 17 — Buttons and buzzer into their collars

Each has a printed pocket on the lid underside. The body seats up inside the
pocket; only the plunger comes through the hole in the outer face.

**Test-fit before gluing.** Press the switch into its pocket and look at the
outer face:

- Plunger stands slightly proud → correct
- Plunger sits below the surface → put a 1–2 mm shim behind the switch (a washer,
  or a hardened blob of hot glue on the pocket floor) to raise it. You cannot
  press what you cannot reach

The engraved labels tell you which is which:

| Engraved | Is | Wired to |
|---|---|---|
| **MODE** | Button 1, "NEXT" in the firmware docs | `D2` |
| **SET** | Button 2, "ACTION" | `D3` |

Buzzer into the round collar with the ring of sound holes. Polarity does not
matter — it is passive.

Hot-glue all three from underneath once the fit is right.

### STEP 18 — Solder six joints

This is the step that wants an iron. Six joints, fifteen minutes.

| From | To |
|---|---|
| Button MODE, a leg on **one** face | Uno `D2` tail |
| Button MODE, a leg on the **opposite** face | `−` rail tail |
| Button SET, a leg on **one** face | Uno `D3` tail |
| Button SET, a leg on the **opposite** face | `−` rail tail |
| Buzzer, either leg | **column 8, lower block** tail |
| Buzzer, other leg | `−` rail tail |

**Opposite faces, always.** A tactile switch's four legs are joined in pairs
inside the body, and the joined pair is the two on the same face. Two wires from
one face ties the pin permanently to ground: you get one spurious long-press at
1.5 s and then nothing, which looks exactly like a dead pin.

**Column 8, not column 12.** Column 12 is where `D8` arrives; the 110 Ω resistor
sits between 12 and 8. Wiring the buzzer to 12 shorts the resistor out and drives
the element straight off the pin.

*No iron at all?* A female Dupont end pushes onto the 12 mm buttons' flat legs
and grips well enough with tape over it. It will not grip the buzzer's thin round
leads. If a button dies a week after assembly, this is why.

### STEP 19 — Socket into the lid

From the **outside**. Body through the opening, plate onto the rim, its own two
screws self-tapping into the slotted tabs wherever they land.

Connect the two 250 mm flying leads from STEP 14 to the socket's `L` and `N`
terminals. Earth empty.

### STEP 20 — Connect the ten low-voltage lid wires

LCD `SDA` → `A4`, `SCL` → `A5`, `VCC` → `+` rail, `GND` → `−` rail, plus the six
button and buzzer tails from STEP 18.

They drop into the **front zone**, over the Arduino. They must not go anywhere
near the mains deck. Bundle them with a cable tie and leave the loop long enough
that the lid lies flat beside the base.

---

# PART F — Test, then close

### STEP 21 — Low-voltage test, lid beside the box

Mains still unplugged. Rocker off. Power the Arduino from USB and repeat
`FINAL_BUILD.md` STEPS 21–25:

| Check | Expected |
|---|---|
| Boot | one chirp, `Smart Socket / Calibrating...` |
| Settles to | `READY 0.00A` |
| Relay | clicks, LED finishes **on** |
| **MODE** tap | screen cycles Detail → Stats → back |
| **SET** held 2 s | `MANUAL POWER OFF`, relay clicks |

Everything here is a fault you just created — a solder joint, a wire in the wrong
column, a button on one face. Fix it now, with the box open.

### STEP 22 — Live test, lid loose

Lid resting in place but **not screwed down**. Rocker off. Plug into the wall,
then switch the rocker on.

`0.00 A` with nothing in the socket. Anything else: rocker off, unplug from the
wall, go back to STEP 15.

Then plug in the Class II laptop charger and confirm you get **0.13 A or more**.
`FINAL_BUILD.md` STEP 40 has the full reading table.

### STEP 23 — Close it

Rocker off. **Unplug from the wall.**

Check before the lid goes down:

- [ ] No wire trapped on the base rim
- [ ] The sleeved rocker pair is tied down and touches no low-voltage wire
- [ ] Nothing low-voltage has strayed above the shelf
- [ ] No bare copper anywhere outside a terminal
- [ ] Both flying leads have slack, and neither is pinched under the socket body

Six M3 × 16 countersunk screws down the left and right edges. The heads sit flush
in the cones. Snug, then stop.

### STEP 24 — Final live check

Repeat STEP 22 with the box closed. Then run the demo — `FINAL_BUILD.md` STEP 43
for the real 15-minute version, STEP 44 for the 3-minute one.

### STEP 25 — Power the finished product

The Arduino runs from **a 5 V phone charger into the left-wall USB slot**, plugged
into a **different outlet**.

Never the socket the relay switches. That is a deadlock, not a preference: the
relay opens, the socket dies, the Arduino dies with it, and nothing is left alive
to close the relay again. Both outlets on the twin socket are fed from the same
terminals, so neither will do.

The firmware is in flash and stays there. The USB lead is carrying power only
from here on — and the left-wall slot means you can still reflash without opening
the box.

---

## Corrections to FINAL_BUILD.md

| Where | Says | Should say |
|---|---|---|
| STEP 53 table | Buzzer to **column 12**, lower | **Column 8**. Column 12 is `D8`; the 110 Ω resistor spans 12–8, and wiring to 12 bypasses it |
| PART 10, STEP 46 | Rocker snaps in, dab of glue | True, but its two mains wires have no route to the mains deck. See STEP 8 above |
| PART 10 | Buttons called NEXT / ACTION | The lid is engraved **MODE** / **SET**. Same buttons, `D2` and `D3` |

The buzzer line is fixed in `FINAL_BUILD.md`. The other two are cross-references.

---

## If it does not work

Faults introduced by boxing, on top of `FINAL_BUILD.md`'s table:

| What you see | Almost certainly |
|---|---|
| A button does nothing | Both wires soldered to the same face of the switch |
| Buzzer much louder or distorted | Wired to column 12 — the 110 Ω resistor is shorted out |
| LCD blank, backlight on | Contrast. The blue screw is now facing into the box — reach it with the lid off |
| `0.00 A` after it worked on the bench | A flying lead pulled out of the socket terminal while closing the lid |
| Intermittent reset when the relay clicks | A lid wire lying across the sleeved mains pair. Re-route and tie |
| Relay never clicks after boxing | One of the six pass-slot wires pinched under the shelf |
| Screw spins forever | Post stripped. Move to a different post, or fill with a matchstick and glue |

## Room left inside

The 18650 bay in the front zone stays empty — a single cell cannot run an Uno.

If you fit the **HC-05** later (`docs/HANDOFF.md` §2), put it on the **lower
deck behind the breadboard**, not in the battery bay: the bay is now beside the
sleeved mains run. There is clear floor there, and it keeps the radio's four
wires entirely in the low-voltage half of the box.

Remember its `TX`/`RX` share pins 0 and 1 with the USB uploader — unplug both
before every reflash.

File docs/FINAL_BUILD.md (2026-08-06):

# Final build — mains smart socket, step by step

This replaces `BUILD_GUIDE.md` and `docs/STAGE2.md`. Those describe the
low-voltage bench rig (18650 + resistor bank) that was used to prove the
firmware. This is the finished product: a plug, a wall socket, and the relay
cutting real wall power when the charging device fills up.

Do the steps in order. Do not skip ahead.

---

## Your parts, by position in the photo

**Row 1, left to right:**

| # | Item | Used? |
|---|---|---|
| 1 | 18650 battery holder | **No** — bench rig only |
| 2 | 40-pin male header strip | **No** |
| 3 | Small 4-pin LED module | **No** |
| 4 | Breadboard | Yes |
| 5 | Bag of resistors | Yes — **one** 110 Ω only |
| 6 | Black rocker switch | Yes — mains master switch |
| 7 | ACS712 current sensor | Yes |
| 8 | Arduino Uno | Yes |
| 9 | 16x2 LCD with I2C backpack | Yes |

**Row 2:** plug, socket faceplate, relay. All three used, all three rewired.

---

## How to read the breadboard positions

Hold the board so the printed numbers read normally — **0 on the left, 60 on
the right**.

- **UPPER BLOCK** = the five rows between the centre channel and the **top**
  pair of rails.
- **LOWER BLOCK** = the five rows between the centre channel and the **bottom**
  pair of rails.
- **`+` RAIL** = on the top pair, the hole row next to the **red** line (the
  upper of the two).
- **`−` RAIL** = on the top pair, the hole row next to the **blue** line (the
  lower of the two).

Row letters are deliberately **not** used. Different boards letter them in
opposite directions — this one runs A–E across the upper block and F–J across
the lower block, which is the reverse of many. Block plus column is
unambiguous on any board.

Positions are written as **column N, upper** or **column N, lower**. Any of the
five rows in that block works: all five holes in one column of one block are the
same electrical point.

Your rails are **split at the middle notch, around column 30**. Everything in
this build stays in the **left half, columns 0–30**. Nothing needs bridging.

All five holes in one column of one block are the same electrical point. So if
your board's letters happen to run the other way round, ignore my letters and
use the column plus the block — it makes no electrical difference. The only
place the row matters is the two buttons, and there the instruction says which
side of the gap.

The bottom pair of rails is **not used at all**.

---

## Safety — read once, obey throughout

1. Nothing goes into the wall until STEP 34.
2. Once it is in the wall, the lid is on and no bare metal is reachable.
3. Every mains joint is inside a screw terminal or a connector strip. No
   twisted-and-taped joints. No mains on the breadboard, ever.
4. The Arduino's USB source is the PC or a power bank — **never** the socket the
   relay switches.
5. The relay switches **LIVE**, never neutral.

**This build has no earth.** Your plug lead is 2-core. The socket's earth
terminal stays empty and must never be linked to neutral. Only
**double-insulated (Class II)** appliances may be plugged in — look for the ⧠
double-square symbol on the charger label, or a two-pin figure-8 lead.

---

# PART 1 — Gather

### STEP 1 — Get these

- An assortment of **M3 self-tapping screws, 8 / 12 / 16 / 20 mm**, plus six
  M3 countersunk around 16 mm for the lid. See PART 10 for what goes where
- Hot glue gun
- A small mains connector strip (chocolate block)
- About **10 female-to-male jumper wires** — the LCD, relay and ACS712 all have
  male header pins, and in the finished box they sit in brackets, not in the
  breadboard
- A **Class II laptop charger** (⧠ symbol) for the demo. A phone charger draws
  about 0.09 A on 230 V and the ACS712-5A cannot see it
- A **5 V USB phone charger** and a **USB-A-to-USB-B cable** — this is what powers
  the Arduino in the finished product, instead of your laptop. See PART 9B

### STEP 2 — Clear the bench

Unplug the Arduino from the PC. Unplug the mains plug from everything. Pull
every wire off the socket faceplate and the relay. Pull the buzzer, the
resistor and both buttons out of the breadboard.

You now have bare parts. The Arduino stays unplugged until STEP 21.

---

# PART 2 — Breadboard

### STEP 3 — Orient the board

Turn the breadboard so the printed numbers read normally, 0 on the left.
Confirm the top pair of rails has the red line above the blue line.

### STEP 4 — Buzzer

Push the buzzer into the **lower block** so one leg is in **column 5** and the
other in **column 8**.

It is a passive buzzer. Polarity does not matter — either leg either way.

The body is about 12 mm across, so it covers roughly columns 4–9 and three rows
deep. Everything below reaches into the row furthest from it, next to the
centre channel.

### STEP 5 — Resistor

Take **one** 110 Ω resistor (bands: brown – brown – black – black – brown).
Bend both legs down. One leg into **column 8, lower block**, the other into
**column 12, lower block**.

Column 8 is where the buzzer's second leg already is, so the resistor is now in
series with the buzzer.

### STEP 6 — Button 1 (NEXT)

Push button 1 into the board **across the centre channel**, so its legs land in
**column 18 and column 20** — two legs in the upper block, two in the lower
block.

Press it flat. It should not rock.

### STEP 7 — Button 2 (ACTION)

Same again, legs in **column 25 and column 27**.

**The pair rule.** A tactile button's four legs are joined in pairs inside the
body, and **the joined pair is the two legs on the same side of the channel**.
So the two wires you attach in STEPS 12–15 must come from **opposite sides of
the channel** — one above, one below. Two wires from the same side is a
permanent short, and the pin will read as stuck-pressed.

---

# PART 3 — Wires on the breadboard

Nine male-to-male jumpers. Arduino still unplugged.

### STEP 8 — Power in

Uno **`5V`** → **`+` rail, hole nearest column 3**

### STEP 9 — Ground in

Uno **`GND`** → **`−` rail, hole nearest column 3**

### STEP 10 — Buzzer drive

Uno **digital 8** → **column 12, lower block**

### STEP 11 — Buzzer return

**column 5, lower block** → **`−` rail**

Use the row furthest from the buzzer body, and any hole in the left half of the
rail — the rail is one electrical point, so column 5 or column 13 makes no
difference. Pick whichever the buzzer body is not sitting over.

### STEP 12 — Button 1 signal

Uno **digital 2** → **column 18, UPPER block**

### STEP 13 — Button 1 ground

**column 20, LOWER block** → **`−` rail**

### STEP 14 — Button 2 signal

Uno **digital 3** → **column 25, UPPER block**

### STEP 15 — Button 2 ground

**column 27, LOWER block** → **`−` rail**

**One wire above the channel, one below.** See the pair rule under STEP 7. Both
wires on the same side ties the pin permanently to ground.

---

# PART 4 — The three modules

Female end on the module pin, male end into the breadboard or the Uno.

### STEP 16 — LCD (4 wires)

| LCD backpack pin | Goes to |
|---|---|
| `GND` | `−` rail, hole nearest column 10 |
| `VCC` | `+` rail, hole nearest column 10 |
| `SDA` | Uno **`A4`** |
| `SCL` | Uno **`A5`** |

`A4` and `A5` are the Uno's only I2C pins. Nothing else works.

### STEP 17 — Relay (3 wires)

| Relay pin | Goes to |
|---|---|
| `GND` | `−` rail, hole nearest column 15 |
| `VCC` | `+` rail, hole nearest column 15 |
| `IN` | Uno **`D7`** |

Leave the relay's three **screw** terminals empty.

### STEP 18 — ACS712 (3 wires)

| ACS712 pin | Goes to |
|---|---|
| `GND` | `−` rail, hole nearest column 20 |
| `VCC` | `+` rail, hole nearest column 20 |
| `OUT` | Uno **`A0`** |

Leave the ACS712's two **screw** terminals empty.

### STEP 19 — Check it against this table

| Uno pin | Goes to |
|---|---|
| `5V` | `+` rail |
| `GND` | `−` rail |
| `A0` | ACS712 `OUT` |
| `A4` | LCD `SDA` |
| `A5` | LCD `SCL` |
| `D2` | column 18, upper |
| `D3` | column 25, upper |
| `D7` | Relay `IN` |
| `D8` | column 12, lower |

| On the `+` rail | On the `−` rail |
|---|---|
| Uno `5V` | Uno `GND` |
| LCD `VCC` | LCD `GND` |
| Relay `VCC` | Relay `GND` |
| ACS712 `VCC` | ACS712 `GND` |
| | column 5, lower (buzzer) |
| | column 20, lower (button 1) |
| | column 27, lower (button 2) |

Everything in columns 0–30. Nothing in the bottom rails.

---

# PART 5 — Firmware

The code is already changed and verified for this build — AC mode on, passive
buzzer driven with `tone()`, taper default set for a real charger. 109/109 core
tests pass and it compiles at 37% flash. **You edit nothing.**

### STEP 20 — Upload

1. Arduino IDE → **File → Open** →
   `C:\Users\kyere\Documents\codes\embedded systems\SmartSocket\SmartSocket.ino`
2. **Tools → Board → Arduino AVR Boards → Arduino Uno**
3. Plug the Arduino into the PC with the USB cable
4. **Tools → Port** → pick the COM port that appears
5. Click the **arrow** button. Wait for `Done uploading`

---

# PART 6 — Bench test. No mains yet.

### STEP 21 — Watch the boot

The LCD shows:

```
Smart Socket
Calibrating...
```

then:

```
READY      0.00A
00:00:00  pk0.00
```

**Backlight on but no characters?** Almost always contrast, and it is worth
knowing what to look for.

Turn the small blue screw on the LCD's back board **slowly through its whole
range, both directions**, and watch for a row of solid dark blocks.

- **Blocks appear at some setting** → the panel is fine. Back the screw off
  until they just fade, and the text will be there
- **No blocks anywhere in the range** → the panel is not being driven at all.
  Check LCD `VCC` on the `+` rail and `GND` on the `−` rail

The I2C address needs no attention: `HalDisplay::begin()` probes `0x27`, and
falls back to `0x3F` if only that one answers the bus. Those are the only two
addresses these backpacks appear at, because the address jumpers ship open — a
PCF8574 lands on `0x27`, a PCF8574A on `0x3F`, and the boards are not marked.

### STEP 22 — Listen for the relay

The relay opens first, then **closes** a moment later once calibration is done.
So you hear a click, and the relay LED finishes **ON**.

That is correct and deliberate. `SocketController::enter(State_Idle)` calls
`relay_.setClosed(true)`, because current is the only way to notice a device
being plugged in — an open relay would make the socket blind.

If the LED is **off** at `READY`, the module is active-HIGH: open
`SmartSocket\src\hal\HalPins.h`, change `RelayActiveLow = true` to `false`, and
upload again.

### STEP 23 — Button 1

Tap it. The screen changes to `Cut at / Taper`. Tap again for `Cutoffs /
Saved`. Tap again to return.

Nothing happens? You used two legs on the same side of the gap. Redo STEP 6.

### STEP 24 — Button 2

Hold it for 2 seconds. Screen shows `MANUAL POWER OFF`, relay clicks. Hold
again for 2 seconds — back to `READY`, relay clicks.

### STEP 25 — Buzzer

The socket **chirps once at power-on**, while `Calibrating...` is on screen. A
short, clear beep.

That chirp exists because nothing else would prove the buzzer works: all three
patterns the socket plays in normal use — plug detected, cutoff, fault — need a
real load, so a dead buzzer would stay hidden until the one moment it has to be
heard. Now every boot tests it.

**Silent?**

1. Check the chain: `D8` → col 12 lower → resistor → col 8 lower → buzzer →
   col 5 lower → `−` rail
2. If the wiring is right, the element's resonant frequency is probably not
   1500 Hz. Upload `BuzzerTest/BuzzerTest.ino`, open **Serial Monitor at 9600**,
   note which tone is loudest, put that number into `BuzzerToneHz` in
   `src/hal/HalIo.h`, and re-upload `SmartSocket.ino`
3. If only the steady-HIGH step of `BuzzerTest` sounds, it is an active buzzer
   after all — revert `HalBuzzer::setSounding` in `HalIo.cpp` to a plain
   `digitalWrite`

**Every one of STEPS 21–25 must work before you touch mains.**

---

# PART 7 — Mains

### STEP 26 — Power down

Unplug the Arduino from the PC. The plug stays out of the wall.

### STEP 27 — Find the LIVE core

Your lead is 2-core white, so both wires look identical. The plug is the only
thing that can tell them apart.

Open the plug. Hold it **face towards you, earth pin at the top**. The
**right-hand** pin is `L` (live). The left is `N` (neutral).

See which wire lands on `L`. **Mark it** — tape, marker, anything.

Switch the wrong one and you switch neutral: the socket's live pin stays live
while the LCD says `POWER CUT`. It looks like it works and it is not safe.

### STEP 28 — Move the relay wire from `NC` to `NO`

You currently have a wire in `COM` and a wire in `NC`. `NC` is backwards.

- **`NC`** is live when the relay is off. A crashed Arduino, a pulled USB lead
  or a dead 5 V rail would all leave the socket permanently live — and the
  firmware opens the relay at boot, so `NC` would switch the socket *on*.
- **`NO`** is dead until the firmware closes the relay. Anything going wrong
  falls back to power off.

Loosen `NC`, move that wire to `NO`. Leave `NC` empty. `COM` stays where it is.

### STEP 29 — Live into the rocker

Plug **LIVE** (the wire you marked) → **rocker blade 1**.

The blades do not fit a breadboard. Strip 15 mm, wrap it tightly round the
blade, tape over it. A spade crimp is better if you have one. Either blade can
be either side.

### STEP 30 — Rocker into the relay

**Rocker blade 2** → relay **`COM`** screw.

### STEP 31 — Relay into the sensor

Relay **`NO`** screw → **ACS712 screw 1**.

Either ACS712 screw can be either side. The firmware uses the size of the
reading, not its direction.

### STEP 32 — Sensor into the socket

**ACS712 screw 2** → socket faceplate **LIVE** terminal.

### STEP 33 — Neutral straight through

Plug **NEUTRAL** → socket faceplate **NEUTRAL** terminal, using the connector
strip.

Socket **EARTH** terminal: leave it **empty**. Write
`NO EARTH — CLASS II ONLY` on the faceplate.

### STEP 34 — Tug every joint

Five mains connections:

```
plug LIVE      -> rocker blade 1
rocker blade 2 -> relay COM
relay NO       -> ACS712 screw 1
ACS712 screw 2 -> socket LIVE
plug NEUTRAL   -> socket NEUTRAL
```

Every screw must be tightened onto **bare metal, not insulation**. Pull each
wire. If it moves, it is not connected. A loose screw is the number one reason
this reads `0.00A` later.

Trace the chain once with your finger, out loud.

---

# PART 8 — First live test

### STEP 35 — Rocker OFF

### STEP 36 — Arduino to the PC

Wait for `READY 0.00A`.

### STEP 37 — Plug into the wall

### STEP 38 — Rocker ON

The LCD must still read **`0.00A`** — nothing is in the socket yet.

Anything else: rocker off, unplug from the wall, go back to STEP 34.

### STEP 39 — Plug in the laptop charger

Class II charger, laptop attached, screen on, battery below about 90%.

You should hear a short beep, see `SETTLE`, then after 5 seconds `CHARGING`
with a live current.

### STEP 40 — Read the current. This is the number everything depends on.

| Reading | Meaning |
|---|---|
| **0.13 A or more** | Good. Go on |
| 0.07 – 0.12 A | Marginal — the socket may not separate charging from full |
| 0.00 A | The mains chain is open. Redo `COM`, `NO`, both ACS712 screws |

The thresholds are sized for **230 V mains**, where every current is 2–3× smaller
than on the old battery rig. A 35 W laptop charger draws 0.15 A. One ADC count is
26 mA, so the whole charging signal is about six counts — see the note at the top
of the threshold block in `Config.h` before changing any of them.

### STEP 41 — Check the threshold

Tap **Button 1** for the Detail screen. `Cut at` is the level it will cut
below. It worked that out from your load by itself.

### STEP 42 — Calibrate, only if the reading is clearly wrong

`SmartSocket\src\core\Config.h`, line `SensorMvPerAmp = 185`:

- Reads too high → raise it (190, 195)
- Reads too low → lower it (180, 175)

Upload again after each change.

---

# PART 9 — The demo

### STEP 43 — Real version, about 15 minutes

Start with the laptop at about 95%. Let it fill. At 100% the charger's draw
falls to whatever the laptop needs to run, the socket sees the drop, waits 90
seconds, then:

```
FULL - POWER CUT
ACTION=check now
```

Three beeps, twice. The relay clicks. Power stays off.

### It re-checks by itself

The socket's only sensor sits **downstream of the relay**, so while power is cut
it is blind — it cannot tell an empty socket from a full laptop from a phone at
5%. Rather than wait for a button press, which is the only input a blind socket
has left, it closes the contacts for **8 seconds** every so often and looks:

- **A real charging current appears** → something has changed, resume charging
- **Little or nothing** → open again and wait

How long it waits depends on what was drawing when power was cut:

| At cutoff | Re-checks every |
|---|---|
| Something still drawing — a device is sitting there, full | **15 min** |
| Nothing drawing — the socket is probably empty | **60 s** |

So plugging something new in starts it within a minute, with no button press.

This is **not** auto-rearming, which would restart the exact trickle charging
this product exists to prevent. Auto-rearming leaves the relay closed; this
closes it for seconds at a time and only stays closed on positive evidence. An
8-second probe every 15 minutes is a 0.9% duty cycle.

**ACTION still works** — tap it to re-check immediately instead of waiting. It
is no longer required.

### STEP 44 — Fast version, about 3 minutes

Put a 4-way extension into the smart socket.

1. Laptop charger **and** a phone charger with a phone on it. Total ≈ 0.5 A
2. Wait **1 full minute**. The firmware refuses to cut before then
3. Unplug the laptop charger. Current drops to ≈ 0.09 A, well under `Cut at`
4. Hands off for 90 seconds. Any bounce back up restarts the 90 s
5. Three beeps, relay clicks, `FULL - POWER CUT`

### STEP 45 — Show the stats

Tap **Button 1** twice: `Cutoffs 1 / Saved 0h01m`.

Tap **Button 2** once to re-arm. Run it again and watch `Taper` change slightly
on the Detail screen. That is the adaptive learning tuning itself to your load.

---

# PART 9B — Powering the finished product

The Arduino cannot stay tethered to your laptop. Here is what it actually needs.

## The upload is one-time

Uploading writes the firmware into the Arduino's **flash memory**, which is
permanent. It survives being unplugged, and it survives being powered from
something else. Once STEP 20 is done you never need the PC again.

After that, the USB cable is carrying **power only**.

## Power it from a 5 V USB phone charger

Any ordinary phone charger plus a USB-A-to-USB-B cable (the square-ended
printer-style plug that fits the Uno). Plug the charger into **a different wall
outlet**, or a multi-way adapter alongside the smart socket's own plug.

That is the whole answer. The enclosure already supports it: the Arduino's
connector edge faces the **left wall**, so the USB socket is reachable with the
box closed.

## Never power it from the socket the relay switches

This one is not a preference, it is a deadlock:

```
relay opens  ->  socket dead  ->  Arduino loses power
             ->  relay cannot be commanded closed  ->  socket stays dead
```

The socket would cut power once and never come back, because the thing that
decides to come back died with it. Both outlets on your twin socket are fed from
the same terminals, so **neither** of them can power the Arduino.

## Why not the battery

The parts list includes an 18650 and a holder, and they are genuinely not usable
here:

- **One cell is 3.7 V.** The Uno needs 7–12 V on `VIN`, or a regulated 5 V on the
  `5V` pin. 3.7 V is too low for either.
- **Two in series is 7.4 V** and would run — `BUILD_GUIDE.md` PART 13 covers it —
  but you have a single-cell holder, and a socket that is supposed to sit on the
  wall permanently would go flat in a day or two.

A mains appliance runs off mains. Leave the holder out.

## Never both at once

USB power and a battery on `VIN` at the same time is how Uno regulators die.
One source only.

---

# PART 10 — Into the enclosure

## What to print

**Three files, all from `enclosure/stl_slim/`:**

| File | Weight |
|---|---|
| `SmartSocket_Base.stl` | ~217 g |
| `SmartSocket_Lid.stl` | ~52 g |
| `SmartSocket_Shelf.stl` | ~71 g |

**Total ~340 g, about 849 GHS at 2.50/g.** Ask the printer for his slicer's
quote at 20% infill — it will be less than that solid-volume figure.

**Do not print** `SmartSocket_Assembly.stl` — it is the parts fused into one
solid, for looking at only. `SmartSocket_FitCheck.stl` is an optional 39 g test
coupon.

All three print flat, as exported, **no supports, do not rotate anything**. The
lid is already flipped. Layer 0.2 mm, 4 perimeters, brim on the base.

Assembled size is **170 × 176 × 61 mm**.

## How the box is arranged

The design keeps 230 V and low voltage in separate compartments, using printed
geometry rather than a partition bolted in later.

| Zone | Height | What lives there |
|---|---|---|
| **Front zone** — LV | full height | Arduino, and the LCD/buttons/buzzer on the lid above it |
| **Lower deck** — LV | Z 0–22 mm | Breadboard, under the shelf |
| **Mains deck** — 230 V | Z 24–56 mm | Socket faceplate, relay, ACS712, on top of the shelf |

**The shelf is the barrier.** Exactly one route crosses it: a 16 × 6 mm slot
carrying **six low-voltage wires and nothing else** — relay `VCC`/`GND`/`IN` and
ACS712 `VCC`/`GND`/`OUT`. No mains wire goes through it.

Two things that changed from the earlier design, so ignore anything that says
otherwise:

- **The socket faceplate mounts into the lid**, not loose on a lead. The lid has
  the opening and slotted fixing holes; the socket's own screws self-tap
  wherever they land, so any fixing centre from 90 to 150 mm works.
- **The rocker snaps straight into the base's front wall.** There are no bezel
  plates any more.

## Screws

All M3 self-tapping into printed pilot holes. Ordinary M3 machine screws cut
their own thread in PLA perfectly well.

| Where | Count | Head |
|---|---|---|
| Lid to base | 6 | countersunk, ~16 mm |
| Shelf to its posts | 6 | pan |
| Arduino to floor standoffs | 4 | pan, ~8 mm |
| LCD to lid bosses | 4 | pan, ~6 mm |

**Buy an assortment of M3 self-tappers in 8 / 12 / 16 / 20 mm.** Cheap, and it
removes the guesswork on lengths.

Also: hot glue, for the two buttons, the buzzer and the rocker.

## Assembly order

Rocker off, plug out of the wall, Arduino unplugged for all of this.

### STEP 46 — Rocker into the front wall

It snaps into the opening in the **base's front wall** from outside. Dab of glue
behind it once it clicks in.

### STEP 47 — Arduino

Four M3 into the floor standoffs in the front zone. **Its connector edge faces
the LEFT wall** so you can reflash without opening the box.

### STEP 48 — Breadboard

Peel the backing and stick it down on the lower deck floor, behind the Arduino.

### STEP 49 — Wire the lower deck now, before the shelf goes on

Once the shelf is screwed down you cannot reach under it without taking it off
again. Do all the breadboard wiring, then feed the **six** relay and ACS712
signal wires up through the pass-slot, leaving plenty of slack on the deck side.

### STEP 50 — Shelf

Drop it onto its eight posts and screw down the six outer ones. The middle pair
is plain support — a screw there could not be reached past the breadboard.

### STEP 51 — Relay and ACS712 onto the shelf

Relay to the left, ACS712 to its right, both in the strip in front of where the
socket will sit. Connect the six signal wires you fed up in STEP 49.

### STEP 52 — Mains cord

In through the round hole in the **back wall, above the shelf**. Beside it are
two small holes: thread a cable tie through them, round the cord, and cinch it.
That is the strain relief — a pull on the lead must never reach a screw terminal.

**The mains cord does not share an opening with anything else.** Each lead has
its own wall, and that separation is the point:

| Wall | Carries | Deck |
|---|---|---|
| **Back** | mains cord, 230 V | above the shelf |
| **Left** | Arduino USB, 5 V | front zone, low voltage |
| **Front** | rocker switch | — |

The Arduino's opening is one wide 15 mm slot cut deliberately loose: the board's
position is exact because the standoffs fix it, but where the USB socket and
barrel jack sit along that edge varies between clones, and one opening clears
both. So the USB lead from the phone charger goes straight in the left wall, and
you can reflash without opening the box.

### STEP 53 — Lid parts

LCD onto its four bosses.

**The buttons and buzzer come off the breadboard and go into the lid.** The lid
has a collar for each: the body seats up inside the pocket and only the plunger
pokes through the 8 mm hole, so you press it from outside a closed box. Hot-glue
each one in from underneath.

Then wire them back down with **150 mm of slack**, so the lid lifts off and sits
beside the box without pulling anything loose:

| From | To |
|---|---|
| Button 1, a leg on one face | Uno digital **2** |
| Button 1, a leg on the **opposite** face | `−` rail |
| Button 2, a leg on one face | Uno digital **3** |
| Button 2, a leg on the **opposite** face | `−` rail |
| Buzzer, either leg | column 8, lower block |
| Buzzer, other leg | `−` rail |

**Column 8, not column 12.** Column 12 is where `D8` arrives and the 110 Ω
resistor spans 12 to 8. Wiring the buzzer to 12 shorts the resistor out and
drives the element straight off the pin.

**The channel rule from STEP 7 no longer applies** — it only existed because the
button's legs bridged the breadboard's centre channel. What survives is the
reason behind it: the two legs on the same face are joined inside the body, so
take one from each face or the pin is tied permanently to ground.

**Getting wire onto the legs.** Solder is the right answer — six joints, fifteen
minutes, and the buzzer's thin round leads grip nothing else well. Borrow an iron
if you can. Failing that, a female Dupont end pushes onto the 12 mm buttons' flat
legs and grips well enough if you tape over it; if a button dies after assembly,
suspect that first.

### STEP 54 — Socket into the lid

From the outside. Its own screws self-tap into the slotted holes.

### STEP 55 — Close up

Wire the mains side to the socket's terminals, then six countersunk M3 down the
left and right edges.

### STEP 56 — Repeat STEPS 35–40

One last live check with the box closed.

## If something is wrong

| What you see | What it means |
|---|---|
| `0.00 A` with a charger plugged in | Open mains chain. Redo `COM`, `NO`, both ACS712 screws |
| Never leaves `READY` | Load under 0.12 A. Bigger charger |
| Cuts at exactly 60 s with no taper | Peak was under 0.25 A, so it took the trickle path. Bigger charger |
| Goes to `READY` instead of `FULL` | Current fell under 0.05 A and read as unplugged. Leave a small load on |
| Cuts too early | `TaperConfirmMs` 90000 → 180000 in `Config.h` |
| Buzzer silent | Trace `D8` → col 12 lower → resistor → col 8 lower → buzzer → col 5 lower → `−` rail |
| A button does nothing at all | Two different faults look identical here. Either the wires are not in the columns the legs actually occupy, or they are both on the same side of the channel — a pin held permanently low fires one `LongPress` at 1.5 s and then nothing, and `loop()` ignores `LongPress` on NEXT. Read the legs, then swap the `D2`/`D3` jumpers at the Uno end to tell pin from button |
| LCD lit but blank | Blue screw on the backpack. Turn it the whole way, both directions, watching for dark blocks |
| LCD dead, no backlight | `VCC`/`GND` on the wrong rails |
| Relay backwards | `RelayActiveLow = false` in `HalPins.h` |
| `! OVERCURRENT !` | Rocker off, unplug from the wall, recheck every mains joint |

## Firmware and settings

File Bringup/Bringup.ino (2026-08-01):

// =====================================================================
//  Bringup.ino - Smart Socket, simple version
//
//  Runs on the Stage 1 wiring: sensor on A0, buttons on D2/D3, relay on
//  D7, buzzer on D8. NO SCREEN NEEDED. Everything is reported over the
//  USB cable instead, so you can build and test before the LCD backpack
//  arrives.
//
//  One file. No libraries to install. Nothing to configure.
//
//  TO USE:
//    1. Upload.
//    2. Tools -> Serial Monitor.
//    3. Set the speed box (bottom right) to 9600 baud.
//
//  The full layered firmware lives in ../SmartSocket/. This is the plain
//  version: same behaviour, no EEPROM learning, no screen.
// =====================================================================

// ---------------------------------------------------------------------
//  PINS - these match the Stage 1 wiring exactly.
// ---------------------------------------------------------------------
const uint8_t PIN_SENSOR     = A0;  // R2 "OUT"
const uint8_t PIN_BTN_NEXT   = 2;   // square one
const uint8_t PIN_BTN_ACTION = 3;   // square two
const uint8_t PIN_RELAY      = 7;   // R1 "IN"
const uint8_t PIN_BUZZER     = 8;   // via resistor to L2 long leg

// Most cheap relay boards switch on when the pin goes LOW. If yours turns
// out backwards - it clicks OFF at startup instead of ON - change this to
// false and re-upload. Nothing else needs to change.
const bool RELAY_ACTIVE_LOW = true;

// ---------------------------------------------------------------------
//  NUMBERS YOU MIGHT TUNE
// ---------------------------------------------------------------------
const int  SENSOR_MV_PER_AMP = 185;    // ACS712 5A model. See "CALIBRATING" below.

// Measurements are averaged over a whole number of 50 Hz mains cycles (20 ms
// each). Mains hum couples into the sensor's leads - its open screw terminals
// are effectively a small antenna - and over a whole cycle the positive and
// negative halves cancel exactly. Average over an arbitrary window instead and
// a residue survives, which drifts and looks like a real current.
//
// MUST stay a whole multiple of 20 ms. Longer is quieter but blocks the button
// polling for that long, so 40 ms is the compromise.
const unsigned int AVG_WINDOW_MS = 40;   // 2 mains cycles
const unsigned int CAL_WINDOW_MS = 500;  // 25 cycles, for the startup zero

// ---------------------------------------------------------------------------
//  THE LOAD IS A STAIRCASE, AND EVERY THRESHOLD BELOW SITS BETWEEN TWO STEPS.
//
//  The "device" is BANK_RESISTORS identical resistors in parallel across one
//  18650, and the charge is made to taper by pulling them out. Measured on this
//  kit: 110 ohm +/-1%, so each one draws 3.7 V / 110 = 33.6 mA and the current
//  can only ever land on a multiple of it:
//
//    resistors in |  1    2    3    4    5    6    7    8    9   10   11
//    current (mA) | 34   67  101  134  168  202  235  269  302  336  370
//
//  One ADC count is 5000 mV / 1024 / 185 mV-per-A = 26 mA - most of a whole
//  step. So a threshold placed ON a step is a coin toss, and the offset drift
//  seen on this hardware is itself several steps wide. Each number below is
//  placed near the middle of a gap. Check the table before changing any of them.
// ---------------------------------------------------------------------------
const int  BANK_RESISTORS    = 11;     // how many are in the load bank
const long PER_RESISTOR_MA   = 34;     // 3.7 V / 110 ohm; only used before a peak exists

const long NOISE_FLOOR_MA    = 60;     // below this, call it zero (under step 2)
const long PLUG_DETECT_MA    = 120;    // above this, something is plugged in (steps 3|4)
// Below the noise floor on purpose: only a reading of exactly zero counts as an
// unplug. Was 80 mA, which sat 13 mA under the 3-resistor step - so the demo's
// own end state was one count of drift away from being read as "unplugged",
// which abandons the session and goes quietly back to READY.
const long UNPLUG_MA         = 50;     // below this, it has been unplugged
const long TAPER_FLOOR_MA    = 115;    // cutoff level never goes below this (steps 3|4)
// 250, not 300: the full bank is 370 mA nominal, but a cell at 3.4 V or a sensor
// reading 15% low puts it near 300. Falling under this does not just mis-tune the
// demo, it takes the trickle branch - power cut at 60 s with no taper and no 90 s
// confirmation, which from the outside looks like a real cutoff.
const long MIN_PEAK_MA       = 250;    // a real charge pulls at least this much
const long OVERCURRENT_MA    = 4500;   // fault: sensor maxes out at 5000
// 49%, matching the full firmware in ../SmartSocket (38% learned x 130% margin).
// Puts the threshold at 181 mA with a full bank - almost exactly halfway between
// step 5 (168) and step 6 (202), the furthest from both it can sit.
const int  TAPER_PCT         = 49;     // cut when current falls under this % of peak

const unsigned long SAMPLE_MS        = 250;      // how often we measure
const unsigned long SETTLE_MS        = 5000;     // ignore the first 5s after plug-in
const unsigned long MIN_CHARGE_MS    = 60000UL;  // never cut off in the first minute
const unsigned long TAPER_CONFIRM_MS = 90000UL;  // current must stay low this long
const unsigned long UNPLUG_CONFIRM_MS= 3000;     // load must be gone this long
const unsigned long PRINT_MS         = 1000;     // how often we report
// Asymmetric on purpose. A press is accepted quickly so taps feel instant,
// but a release must be stable for much longer before it counts.
//
// Cheap tactile switches on a breadboard chatter: contact drops out for a few
// milliseconds at a time while you are holding them down. With a symmetric
// 30 ms filter every dropout read as a release and restarted the long-press
// timer, so a 1.5 s hold could take ten seconds of wrestling to register - or
// never register at all. Ignoring any gap shorter than RELEASE_FILTER_MS makes
// a hold accumulate properly through the chatter.
const unsigned long PRESS_FILTER_MS   = 25;
const unsigned long RELEASE_FILTER_MS = 120;
const unsigned long LONG_PRESS_MS     = 1500;

// ---------------------------------------------------------------------
//  STATE
// ---------------------------------------------------------------------
enum State {
  READY,       // power on, nothing plugged in
  SETTLE,      // load just appeared, waiting for it to steady
  CHARGING,    // measuring, watching for the drop
  CUT,         // full - power cut, waiting for the user
  MANUAL_OFF,  // user forced power off
  FAULT        // overcurrent
};

State state = READY;

int  zeroCounts   = 512;  // measured at startup
long currentMa    = 0;
long peakMa       = 0;
long thresholdMa  = 0;

unsigned long stateSince   = 0;  // when we entered the current state
unsigned long chargeStart  = 0;  // when CHARGING began
unsigned long lowSince     = 0;  // when current first dropped below threshold (0 = not low)
unsigned long goneSince    = 0;  // when the load first vanished (0 = still there)
unsigned long lastSample   = 0;
unsigned long lastPrint    = 0;
unsigned long cutoffCount  = 0;

// ---------------------------------------------------------------------
//  RELAY
// ---------------------------------------------------------------------
void powerOn() {
  digitalWrite(PIN_RELAY, RELAY_ACTIVE_LOW ? LOW : HIGH);
}

void powerOff() {
  digitalWrite(PIN_RELAY, RELAY_ACTIVE_LOW ? HIGH : LOW);
}

// ---------------------------------------------------------------------
//  BUZZER
//
//  Driven with tone() rather than a plain HIGH. A PASSIVE buzzer is just a
//  coil and needs a switching signal - a steady voltage does nothing but
//  click. An ACTIVE buzzer has its own oscillator, but still sounds when fed
//  a square wave. So tone() drives both types, whereas digitalWrite only
//  drives active ones. The two look identical from the outside, so this
//  removes the guesswork.
//
//  tone() uses Timer2. millis() uses Timer0, so there is no clash.
// ---------------------------------------------------------------------
// Measured on the actual buzzer with BuzzerTest.ino: 1500 Hz was clearly the
// loudest, 2400 Hz was faint, and 3000 Hz and above were inaudible. A passive
// buzzer is a resonant device - a few hundred Hz off its peak is the difference
// between a clear beep and nothing at all. Do not "round this to a nicer
// number" without re-running BuzzerTest.
const unsigned int BUZZER_TONE_HZ = 1500;

void beep(int times, int onMs, int offMs) {
  for (int i = 0; i < times; i++) {
    tone(PIN_BUZZER, BUZZER_TONE_HZ);
    delay(onMs);
    noTone(PIN_BUZZER);
    digitalWrite(PIN_BUZZER, LOW);
    if (i < times - 1) delay(offMs);
  }
}

// ---------------------------------------------------------------------
//  BUTTONS
//
//  Wired to GND and using the chip's internal pull-up resistors, so a
//  pressed button reads LOW. That is why there are no resistors on them.
// ---------------------------------------------------------------------
// poll() is a member rather than a free function on purpose. The Arduino IDE
// auto-generates prototypes for free functions and inserts them ABOVE this
// struct, so a free `pollButton(Button&, ...)` fails to compile with
// "'Button' was not declared in this scope". Members are immune to that.
struct Button {
  uint8_t pin;
  bool    down;       // the debounced state we act on
  bool    longFired;  // long press already reported for this hold
  bool    pending;    // raw disagrees with `down`, waiting out the filter
  unsigned long edgeAt;   // when raw first started disagreeing
  unsigned long downAt;   // when the debounced press began

  // Adopt whatever the pin reads right now as the starting state, and mark any
  // already-held button as having spent its long press. Without this, a button
  // that is stuck LOW at boot fires a long press 1.5 s later all by itself -
  // which looks exactly like a mysterious spontaneous power-off.
  void begin(unsigned long now) {
    down = (digitalRead(pin) == LOW);
    longFired = down;
    pending = false;
    edgeAt = now;
    downAt = now;
  }

  bool stuck() const { return digitalRead(pin) == LOW; }

  // Returns 1 on release-after-short-press (a tap), 2 the moment a long
  // press is reached, 0 otherwise.
  int poll(unsigned long now) {
    bool raw = (digitalRead(pin) == LOW);

    if (raw == down) {
      pending = false;          // settled again, forget any part-formed edge
    } else {
      if (!pending) {
        pending = true;
        edgeAt = now;
      }
      unsigned long needed = raw ? PRESS_FILTER_MS : RELEASE_FILTER_MS;
      if (now - edgeAt >= needed) {
        pending = false;
        down = raw;
        if (down) {
          downAt = now;
          longFired = false;
        } else if (!longFired) {
          return 1;             // a tap: released before the long-press point
        }
      }
    }

    if (down && !longFired && (now - downAt >= LONG_PRESS_MS)) {
      longFired = true;
      return 2;
    }
    return 0;
  }
};

Button btnNext   = { PIN_BTN_NEXT,   false, false, false, 0, 0 };
Button btnAction = { PIN_BTN_ACTION, false, false, false, 0, 0 };

// ---------------------------------------------------------------------
//  CURRENT MEASUREMENT
//
//  The sensor sits at half its supply with no current flowing, and moves
//  up or down from there depending on which way the current runs. So we
//  measure that resting point once at startup (with the relay open, so it
//  really is zero) and everything after is the difference from it.
// ---------------------------------------------------------------------
// Samples flat out for windowMs, however many readings that turns out to be.
// Timing the window rather than counting samples is the whole point: it is what
// guarantees a whole number of mains cycles regardless of how fast analogRead
// happens to be.
int readRawAverage(unsigned int windowMs) {
  unsigned long total = 0;
  unsigned long count = 0;
  unsigned long window = (unsigned long)windowMs * 1000UL;
  unsigned long start = micros();

  while (micros() - start < window) {
    total += analogRead(PIN_SENSOR);
    count++;
  }
  if (count == 0) return analogRead(PIN_SENSOR);  // cannot happen, but never divide by zero
  return (int)(total / count);
}

long readCurrentMa() {
  int raw = readRawAverage(AVG_WINDOW_MS);
  int diff = raw - zeroCounts;
  if (diff < 0) diff = -diff;  // direction does not matter, only size

  // counts -> millivolts -> milliamps, in two steps so nothing overflows
  long mv = (long)diff * 5000L / 1024L;
  long ma = mv * 1000L / (long)SENSOR_MV_PER_AMP;

  if (ma < NOISE_FLOOR_MA) ma = 0;  // too small to tell from noise
  return ma;
}

// ---------------------------------------------------------------------
//  REPORTING
// ---------------------------------------------------------------------
const char *stateName() {
  switch (state) {
    case READY:      return "READY";
    case SETTLE:     return "SETTLE";
    case CHARGING:   return "CHARGING";
    case CUT:        return "FULL - POWER CUT";
    case MANUAL_OFF: return "MANUAL OFF";
    case FAULT:      return "! OVERCURRENT !";
  }
  return "?";
}

// How many resistors the reading implies are still in the bank.
//
// Worked out from the session peak rather than from PER_RESISTOR_MA, so it stays
// right even when the sensor calibration or the cell voltage is off - both of
// those scale the whole staircase, and dividing by the peak cancels them out.
//
// This is the number that makes the demo debuggable: if the serial line says 5
// while there are 7 resistors in the board, the reading is wrong, not the logic.
int resistorsLeft(long ma) {
  long stepMa = (peakMa > 0) ? (peakMa / BANK_RESISTORS) : PER_RESISTOR_MA;
  if (stepMa <= 0) return 0;
  return (int)((ma + stepMa / 2) / stepMa);
}

void printAmps(long ma) {
  Serial.print(ma / 1000);
  Serial.print('.');
  long frac = (ma % 1000) / 10;
  if (frac < 10) Serial.print('0');
  Serial.print(frac);
  Serial.print('A');
}

void report(unsigned long now) {
  Serial.print('[');
  Serial.print(stateName());
  Serial.print("]  now ");
  printAmps(currentMa);

  if (state == CHARGING || state == SETTLE) {
    Serial.print("  (~");
    Serial.print(resistorsLeft(currentMa));
    Serial.print(" of ");
    Serial.print(BANK_RESISTORS);
    Serial.print(" resistors)");
  }

  if (state == CHARGING) {
    Serial.print("   peak ");
    printAmps(peakMa);
    Serial.print("   cut below ");
    printAmps(thresholdMa);
    Serial.print("   running ");
    Serial.print((now - chargeStart) / 1000);
    Serial.print('s');

    // The trickle branch cuts power at 60 s with no taper and no confirmation,
    // which is indistinguishable from a real cutoff unless it is called out here.
    if (peakMa < MIN_PEAK_MA) {
      Serial.print(F("   *** PEAK TOO LOW - will be cut as a trickle at 60s."
                     " Add resistors. ***"));
    }
    if (lowSince != 0) {
      Serial.print("   LOW for ");
      Serial.print((now - lowSince) / 1000);
      Serial.print("s of ");
      Serial.print(TAPER_CONFIRM_MS / 1000);
      Serial.print('s');
    }
  }
  Serial.println();
}

void enter(State s, unsigned long now) {
  state = s;
  stateSince = now;
}

// ---------------------------------------------------------------------
//  SETUP
// ---------------------------------------------------------------------
void setup() {
  // Relay first, before anything else, so a reset never leaves it closed.
  pinMode(PIN_RELAY, OUTPUT);
  powerOff();

  pinMode(PIN_BUZZER, OUTPUT);
  digitalWrite(PIN_BUZZER, LOW);

  pinMode(PIN_BTN_NEXT,   INPUT_PULLUP);
  pinMode(PIN_BTN_ACTION, INPUT_PULLUP);

  Serial.begin(9600);
  while (!Serial) { }  // harmless on an Uno, needed on some clones

  Serial.println();
  Serial.println(F("================================================"));
  Serial.println(F(" Smart Socket - simple version"));
  Serial.println(F("================================================"));
  Serial.println(F(" A0 sensor   D2 button1   D3 button2"));
  Serial.println(F(" D7 relay    D8 buzzer"));
  Serial.println();

  // Close the relay FIRST, then measure zero.
  //
  // The relay coil draws ~70 mA, and that current flows through the shared
  // ground wiring on the breadboard. The small voltage drop it creates shifts
  // the sensor's ground relative to the Arduino's, and the ADC reads that shift
  // as current. Calibrating with the coil de-energised and then running with it
  // energised bakes that offset into every later reading - it showed up as a
  // steady phantom 0.10-0.12 A.
  //
  // Nothing is plugged in at this point, so the relay closing is harmless and
  // "socket live, waiting" is the normal resting state anyway. Measuring here
  // means the zero is taken in exactly the condition it will be used in.
  powerOn();
  delay(300);   // let the coil current and the rail settle

  Serial.print(F("Calibrating sensor zero... "));
  zeroCounts = readRawAverage(CAL_WINDOW_MS);
  Serial.print(F("done. resting value = "));
  Serial.println(zeroCounts);

  if (zeroCounts < 400 || zeroCounts > 620) {
    Serial.println(F("*** WARNING: expected about 512."));
    Serial.println(F("*** Check A0, and the sensor's VCC and GND wires."));
  }

  Serial.println();
  // Nothing should be pressed at boot. Anything reading LOW here is wired
  // wrong, not being held by the user.
  Serial.println();
  Serial.print(F("Button1 (D2): "));
  Serial.println(btnNext.stuck()   ? F("*** STUCK PRESSED - MISWIRED ***") : F("ok, released"));
  Serial.print(F("Button2 (D3): "));
  Serial.println(btnAction.stuck() ? F("*** STUCK PRESSED - MISWIRED ***") : F("ok, released"));

  if (btnNext.stuck() || btnAction.stuck()) {
    Serial.println(F("  A stuck button means its two wires reach legs that are"));
    Serial.println(F("  joined INSIDE the switch. Rotate the switch a quarter"));
    Serial.println(F("  turn and re-seat it, then restart."));
  }

  btnNext.begin(millis());
  btnAction.begin(millis());

  Serial.println();
  // The demo in one place, worked out from the constants rather than written down,
  // so it can never disagree with them.
  {
    const int cutAt  = (TAPER_PCT * BANK_RESISTORS - 1) / 100;  // highest count that cuts
    const int target = cutAt - 1;                               // one step of slack
    Serial.print(F("Load bank: "));
    Serial.print(BANK_RESISTORS);
    Serial.print(F(" x 110 ohm = "));
    printAmps((long)BANK_RESISTORS * PER_RESISTOR_MA);
    Serial.println();
    Serial.print(F("Demo: start with all "));
    Serial.print(BANK_RESISTORS);
    Serial.print(F(" in, wait 1 min, then pull down to "));
    Serial.print(target);
    Serial.println(F(" and keep your hands off for 90 s."));
    Serial.print(F("  cuts at "));
    Serial.print(cutAt);
    Serial.print(F(" or fewer; never go below 3 - at 2 it reads as unplugged."));
    Serial.println();
  }
  Serial.println();
  Serial.println(F("Button1 = cycle info   Button2 = tap to reset, hold 2s for on/off"));
  Serial.println(F("Or type into the box above:  n = button1   a = button2 tap   h = button2 hold"));
  Serial.println(F("                            z = re-zero the sensor"));
  Serial.println(F("------------------------------------------------"));

  // Relay is already closed - it was closed before calibration, above.
  beep(1, 250, 0);
  enter(READY, millis());
}
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
void loop() {
  unsigned long now = millis();

  // Buttons are polled every pass so taps are never missed.
  // Keyboard equivalents of the buttons, typed into the Serial Monitor. These
  // exist so a faulty button can never leave you with no way to drive the
  // socket - and so the state machine can be exercised independently of the
  // button wiring while that wiring is still being debugged.
  while (Serial.available() > 0) {
    char c = Serial.read();
    if (c == 'n' || c == 'N') {
      Serial.print(F(">> [key] button1. cutoffs so far: "));
      Serial.println(cutoffCount);
    } else if (c == 'a' || c == 'A') {
      Serial.println(F(">> [key] button2 tap"));
      onActionTap(now);
    } else if (c == 'h' || c == 'H') {
      Serial.println(F(">> [key] button2 hold"));
      onActionHold(now);
    } else if (c == 'z' || c == 'Z') {
      // Re-measure the zero point without restarting. Useful for telling a
      // fixed offset apart from genuine wander: if a phantom reading vanishes
      // after 'z' and stays away, it was an offset; if it creeps back, it is
      // drift or a loose connection.
      Serial.print(F(">> [key] re-zeroing (keep the load disconnected)... "));
      zeroCounts = readRawAverage(CAL_WINDOW_MS);
      Serial.print(F("resting value = "));
      Serial.println(zeroCounts);
    }
  }

  int a = btnAction.poll(now);
  if (a == 1) onActionTap(now);
  if (a == 2) onActionHold(now);

  int n = btnNext.poll(now);
  if (n == 1) {
    Serial.print(F(">> button1 works. cutoffs so far: "));
    Serial.println(cutoffCount);
  }

  if (now - lastSample >= SAMPLE_MS) {
    lastSample = now;
    step(now);
  }

  if (now - lastPrint >= PRINT_MS) {
    lastPrint = now;
    report(now);
  }
}

// =====================================================================
//  CALIBRATING
//
//  With a known load connected, compare the reported amps against a
//  multimeter. If the reading is consistently too HIGH, raise
//  SENSOR_MV_PER_AMP (try 190, 195). Too LOW, lower it (180, 175).
//  Re-upload after each change.
//
//  If it reports current with nothing connected, unplug the USB and plug
//  it back in - the zero point is measured fresh at every startup.
// =====================================================================

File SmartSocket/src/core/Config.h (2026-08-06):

// Config.h - every tunable constant for the smart socket, in one place.
// Portable C++: must not include Arduino.h.
//
// Tuning guide is in docs/TUNING.md. The values that matter most in the field are
// TaperConfirmMs and TaperRatioDefaultPct.
#ifndef SMARTSOCKET_CORE_CONFIG_H
#define SMARTSOCKET_CORE_CONFIG_H

#include <stdint.h>

namespace smartsocket {
namespace config {

// The pin map lives in src/hal/HalPins.h, not here: pin names like A0 are Arduino
// macros, and this header must stay free of Arduino.h so the core can be compiled
// and tested natively.

// ---------------------------------------------------------------------------
// ACS712 current sensor (5 A model)
// ---------------------------------------------------------------------------
// Datasheet sensitivity: 185 mV per amp for the 5 A variant.
const int32_t SensorMvPerAmp = 185;

// Uno ADC: 10-bit over a 5 V reference.
const int32_t AdcMaxCounts = 1024;
const int32_t AdcRefMv = 5000;

// How long the zero-offset calibration averages for.
//
// TIME-BASED, AND A WHOLE NUMBER OF MAINS CYCLES, FOR TWO REASONS.
//
// 1. Any AC load current present cancels instead of biasing the offset, because
//    a sine wave averages to zero over whole cycles. That is what makes it safe
//    to calibrate with the relay CLOSED - which it must be, because closed is
//    the condition the socket actually operates in.
// 2. A fixed sample count spans a whole number of cycles only by luck, and the
//    leftover part-cycle biases the result by an amount that wanders with phase.
//
// 100 ms = 5 cycles at 50 Hz.
const uint16_t ZeroCalibrationMs = 100;

// Samples thrown away before averaging starts. The relay has just closed, and
// its coil takes a few milliseconds to settle into a steady draw - which is the
// whole point of calibrating with it closed.
const uint16_t ZeroCalibrationDiscard = 64;

// How far the continuously tracked zero may sit from mid-scale before it is
// rejected. The ACS712 idles at VCC/2 by construction, so 100 counts - about
// half a volt - is not drift, it is a disconnected sensor or a broken supply,
// and following it would be a runaway.
const int32_t ZeroTrackingLimitCounts = 100;

// AC RMS sampling window. Ghana mains is 50 Hz = 20 ms per cycle; 60 ms spans
// exactly 3 whole cycles, which avoids the partial-cycle bias that would make the
// reading wander with phase.
//
// Kept at 3 cycles rather than 5 because this sampling loop blocks: every
// millisecond here is a millisecond loop() cannot poll the buttons, so a longer
// window starts swallowing short taps. Three cycles is enough to average cleanly
// and leaves the UI responsive. MUST stay a whole multiple of 20 ms.
const uint16_t AcRmsWindowMs = 60;
const uint16_t MainsFrequencyHz = 50;

// Samples averaged per DC reading.
const uint16_t DcAverageSamples = 64;

// Readings below this are clamped to zero rather than pretending to precision we
// do not have.
//
// 30 mA, MEASURED, not assumed. With the clamp temporarily removed an empty
// socket read 0.00 A for five minutes with a single excursion to 0.02 - so the
// pedestal is under one ADC count, and this sits at 1.5x the worst reading seen.
//
// The old value was 60, inherited from the battery rig, and it assumed one
// reading equals one ADC count equals 26 mA. That is wrong for AC mode:
// AcRmsCurrentSensor sums squares over roughly 500 samples, and averaging drives
// quantisation noise well below a single count.
//
// It was also masking a real bug. Before the zero offset was fixed - calibrated
// with the relay open, then frozen at boot - an empty socket read 0.08-0.13 A
// and drifted. A 60 mA floor hid that most of the time, which is exactly what a
// noise floor should never be used for.
const int32_t NoiseFloorMa = 30;

// ---------------------------------------------------------------------------
// Charge detection thresholds
// ---------------------------------------------------------------------------
// THE LOAD IS A STAIRCASE, AND EVERY THRESHOLD HERE SITS BETWEEN TWO STEPS.
//
// This socket's "device" is a bank of 11 identical resistors in parallel across
// one 18650, and a charge is made to taper by pulling them out one at a time.
// The resistors were measured at 110 ohm +/-1%, so each one draws
// 3.7 V / 110 = 33.6 mA and the current can only ever land on a multiple of it:
//
//   resistors in |  1    2    3    4    5    6    7    8    9   10   11
//   current (mA) | 34   67  101  134  168  202  235  269  302  336  370
//
// One ADC count is 5000 mV / 1024 / 185 mV-per-A = 26 mA - most of a whole
// step. A threshold placed ON a step is therefore a coin toss, and the offset
// drift measured on this hardware (a phantom 100-120 mA before the zero
// calibration was moved after the relay closes) is several steps wide. So each
// threshold is placed as near as possible to the middle of a gap. Check the
// table above before changing any of them.
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

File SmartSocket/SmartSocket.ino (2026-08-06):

// =====================================================================
//  Smart Socket with Adaptive Time-of-Use Scheduling
//
//  This file is only the composition root: it constructs the hardware objects
//  and injects them into the logic in src/core/, which contains no Arduino
//  code and is unit-tested on a PC. Read src/core/SocketController.cpp for the
//  state machine and src/core/ChargeAnalyzer.cpp for the algorithm.
//
//  SETUP: see README.md. Requires the LiquidCrystal_I2C library.
// =====================================================================

#include <avr/wdt.h>

#include "src/core/ButtonDebouncer.h"
#include "src/core/BuzzerDriver.h"
#include "src/core/Config.h"
#include "src/core/SocketController.h"
#include "src/core/Types.h"
#include "src/core/UiPresenter.h"
#include "src/hal/HalCurrent.h"
#include "src/hal/HalDisplay.h"
#include "src/hal/HalIo.h"
#include "src/hal/HalPins.h"
#include "src/hal/HalProfileStore.h"
#include "src/hal/HalTelemetry.h"

using namespace smartsocket;

// ---------------------------------------------------------------------
//  SENSOR MODE  -- the one setting you are most likely to change.
//
//    1 = AC true RMS. For the 230 V mains build: plug -> rocker -> relay ->
//        ACS712 -> wall socket. THIS IS WHAT THIS PROJECT NOW RUNS.
//    0 = DC mean.     For the old low-voltage bench rig (18650 + resistor bank),
//        kept so that rig can still be rebuilt.
//
//  This is not cosmetic. AC current is a sine wave that averages to about zero
//  whatever the load, so DC mode on mains reads an empty socket while a laptop
//  charges. Match it to what is actually wired.
//
//  (The #ifndef guard only exists so both paths can be build-tested; in the IDE
//  just change the number.)
// ---------------------------------------------------------------------
#ifndef SENSOR_MODE_AC
#define SENSOR_MODE_AC 1
#endif

// ---------------------------------------------------------------------
//  FITTED PERIPHERALS  -- set each to 1 as the part actually goes in.
//
//  The socket is a complete product with none of these: the sensor, the relay
//  and the LCD are the whole safety-critical path, and cutting power at full
//  charge needs nothing else. Buttons, buzzer and radio are how a person hears
//  about it and talks back, so each is compiled in only once it exists.
//
//  What each 0 costs, and what stands in for it:
//
//    HAS_BUTTONS 0 - no NEXT, so the three LCD screens rotate on a timer
//                    (config::UiAutoCycleMs); no ACTION, so re-arm / cut / probe
//                    come over the serial link instead, which is why the
//                    telemetry object is built either way. Nothing is lost: the
//                    cutoff itself is automatic and the recovery probe is on a
//                    timer, so an untouched socket still does its whole job.
//
//    HAS_BUZZER  0 - cutoffs and faults are silent. They are still on the LCD
//                    and still in the telemetry, so nothing is unreported, but a
//                    fault you are not in the room for will not call you.
//
//    HAS_BLUETOOTH 0 - the same telemetry goes out of the USB port instead of
//                    the HC-05, at config::TelemetryBaud. Open the Arduino IDE's
//                    Serial Monitor at 9600 with line ending "Newline" and it is
//                    the control panel: C, R, P, ? one letter per line. A short
//                    human banner is printed at boot; it is compiled out when the
//                    radio is fitted, so the phone only ever sees clean S,... lines.
//
//  WHEN THE HC-05 GOES ON: it lands on pins 0/1, the same UART the USB port
//  uses. Uploads fail with it wired. Unplug its TX/RX for every upload.
// ---------------------------------------------------------------------
#ifndef HAS_BUTTONS
#define HAS_BUTTONS 0
#endif

#ifndef HAS_BUZZER
#define HAS_BUZZER 0
#endif

#ifndef HAS_BLUETOOTH
#define HAS_BLUETOOTH 1
#endif

// --- hardware ---
HalClock g_clock;
HalRelay g_relay(pins::Relay, pins::RelayActiveLow);
HalDisplay g_display(config::LcdI2cAddress, config::LcdColumns, config::LcdRows);
HalProfileStore g_store(0);
HalTelemetry g_telemetry(config::TelemetryBaud);

#if HAS_BUZZER
HalBuzzer g_buzzer(pins::Buzzer);
#endif

#if HAS_BUTTONS
HalButtons g_buttons(pins::ButtonNext, pins::ButtonAction);
#endif

#if SENSOR_MODE_AC
AcRmsCurrentSensor g_sensor(pins::CurrentSensor);
#else
DcCurrentSensor g_sensor(pins::CurrentSensor);
#endif

// --- logic (no hardware knowledge) ---
SocketController g_controller(g_clock, g_sensor, g_relay, g_store);
UiPresenter g_ui;

#if HAS_BUTTONS
ButtonBank g_buttonBank(g_buttons);
#endif

#if HAS_BUZZER
BuzzerDriver g_buzzerDriver(g_buzzer);
#endif

static Millis g_lastLcdMs = 0;

static void refreshDisplay(bool force) {
  const Millis now = g_clock.now();
  if (!force && (now - g_lastLcdMs) < config::LcdRefreshMs) {
    return;
  }
  g_lastLcdMs = now;

  char line0[LineBufferSize];
  char line1[LineBufferSize];
  g_ui.render(g_controller.status(), line0, line1);
  g_display.showLine(0, line0);
  g_display.showLine(1, line1);
}
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

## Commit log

2026-08-01 feat: smart socket working on 230 V mains
    Project 38 - Arduino Uno socket that cuts wall power when a charging device
    tapers off, so it never trickle-charges.
    Confirmed on hardware: a laptop charged to 95%, the socket detected the taper,
    cut power and latched. 123/123 core tests, 41% flash / 40% RAM.
    Firmware
    - AC true RMS sampling for 230 V mains
    - Thresholds sized against measured mains currents, not the old 3.7 V rig. At
    the old values a normally-charging laptop fell under MinSessionPeakMa and was
    cut at 60 s as an "already full" device - a false cutoff indistinguishable
    from a real one except that Cutoffs does not increment
    - Passive buzzer driven with tone(), plus a power-on chi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
    [SmartSocket_Assembly.stl, SmartSocket_Base.stl, SmartSocket_FitCheck.stl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]
2026-08-01 docs: capture the mobile app plan and project context for a fresh session
    The repo carried the firmware but none of the reasoning around it, so someone
    cloning it would have had to rediscover the hardware limits and the app design
    from scratch.
    docs/MOBILE_APP.md
    - The Uno has no radio and the kit contains none, checked against the kit
    photographs. Nothing can talk to an app until an HC-05 is bought
    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
2026-08-01 docs: correct the cable entries in the assembly steps
    STEP 52 said both mains cables leave through the left-wall opening, which was
    carried over from the old single-deck box. In the current design each lead has
    its own wall: mains through the back above the shelf with a cable-tie strain
    relief, Arduino USB through the left wall in the low-voltage front zone, rocker
    in the front. Keeping them apart is the point, so describing them as sharing an
    opening undid it.
2026-08-01 docs: spell out how the buttons move to the lid
    STEP 53 said to wire the buttons back to 'the same columns', which is wrong and
    hides the part that matters: off the breadboard, the centre-channel rule from
    STEP 7 stops applying, because it only existed to exploit the button's own legs
    bridging the channel. What survives is the reason behind it - the two legs on
    one face are joined inside the body. Lists the six connections, and says plainly
    that this needs solder.
2026-08-01 feat: telemetry link over the hardware UART
    Adds ITelemetry to the core and HalTelemetry over Serial, so a phone - or a
    serial monitor, or anything else - can watch the socket and command it.
    - Status line every second: state ordinal, current, peak, threshold, elapsed,
    cutoffs, saved, relay. Comma-separated integers rather than JSON, because a
    parser costs flash this part cannot spare and the client has the enum names
    - Commands C/R/P/? routed through SocketController::onRemote, which reuses the
    button transitions. A phone must not be able to reach a state the front panel
    cannot, and no safety rule should have a second implementation
    - A stuck relay is unreachable remotely. A welded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
    [Config.h, HalTelemetry.cpp, SmartSocket.ino]
2026-08-01 feat(android): Smart Socket app, gold on black
    Native Android app that talks to the socket over Bluetooth Classic, shows what
    it is doing, and tells it when to cut. Builds to a real APK.
    Screens
    - Splash, three-page onboarding, device picker, dashboard
    - Dashboard leads with the current as a 64pt number, then a taper bar showing
    where it sits between the cutoff threshold and the session peak. That bar is
    the one chart worth drawing: the whole product is "watch this fall past that
    line", and a number alone does not show how close it is
    The feature the sensor cannot provide
    - A phone charging on 230 V draws ~20 mA, inside the ACS712-5A's noise, so the
    socket cannot tell a charging ph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
2026-08-01 feat(android): background service, cutoff notifications, charge history
    The three things left out of the first build, and the reason they were left out:
    they are not add-ons, they are an ownership change.
    Background
    - SocketRepository moves the link onto the Application. A connection owned by a
    ViewModel dies with the screen and can only ever notify someone already
    looking at it, which makes "tell me when charging finishes" impossible by
    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
2026-08-01 fix: set NoiseFloorMa from the measurement, 0 -> 30 mA
    It was left at 0 for the M1 measurement build and never put back - a clamp of
    zero is not a release value.
    Measured: with the clamp out of the way an empty socket read 0.00 A for five
    minutes with one excursion to 0.02, so the pedestal is under a single ADC count
    and 30 sits at 1.5x the worst reading seen.
    The old 60 assumed one reading equals one count equals 26 mA, which is wrong for
    AC mode - the RMS window averages ~500 samples and drives quantisation noise
    well below a count. It was also masking the frozen zero-offset bug, which had an
    empty socket reading 0.08-0.13 A and drifting. A noise floor should never be
    doing that job.
    12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
    [Config.h]
2026-08-06 chore: ignore build output, signing material and stray screenshots
    The desktop app's bin/obj/publish trees, the collected dist/ installers, the
    release keystore and its password file, and the screenshots that accumulate in
    the root while debugging hardware.
    The keystore in particular must never be committed: together with
    keystore.properties it can publish an update Android accepts as genuine.
2026-08-06 feat(firmware): let a connected client own the full-charge decision
    The taper rule cuts on a guess made from 26 mA of resolution. A charging
    laptop draws about 150 mA against a MinSessionPeakMa of 120 - under two ADC
    counts of margin - and inside that margin it cannot reliably tell a charging
    laptop from a full one. When it gets that wrong it cuts a laptop off at 17%,
    which is far worse than not cutting at all.
    A client that reports a real battery percentage has the number the sensor was
    only ever a proxy for. Two new commands hand it the decision:
    A1 / A0 take and hand back the full-charge decision
    B<0-100> the client's own battery level, for the display
    While the claim stands the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
    [Config.h, HalTelemetry.cpp, SmartSocket.ino]
2026-08-06 feat(desktop): Windows app, Bluetooth LE, and a charge window
    C# / .NET 8 with WPF, chosen for how directly it reaches Windows: P/Invoke and
    WinRT are ordinary code rather than a foreign-function shim, the battery comes
    from GetSystemPowerStatus with no WMI dependency, the tray keeps the socket
    watched with the window closed, and it publishes as one self-contained .exe with
    no runtime to install first.
    SmartSocket.Core targets plain net8.0, not net8.0-windows, so the compiler
    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
2026-08-06 feat(android): Bluetooth LE transport, charge window, background hardening
    THE BATTERY CUTOFF DID NOT SURVIVE THE APP BEING SWIPED AWAY. maybeCutForBattery
    and its ACTION_BATTERY_CHANGED receiver lived in SocketViewModel, which is
    activity-scoped, so onCleared unregistered them - while SocketService kept the
    link up and the notification refreshing, so nothing looked wrong. Pressing Home
    worked; swiping away silently did not, and that is the one feature the app exists
    for. Both now live in a BatteryWatcher owned by the Application, beside the
    repository that was already Application-scoped for exactly this reason.
    Service start/stop moved there too. Started from the ViewModel it was left
    runn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
    [BleSerialProfile.kt]
2026-08-06 docs: record that the module is BLE, and where the cutoff now lives
    The single most expensive thing learned this session, and the one thing not
    inferable from the code: the Bluetooth module is not an HC-05. It is sold as
    one, on a ZS-040 board with the button, and it is an HM-10 class BLE part -
    CC2541, service FFE0, characteristic FFE1. Anyone who assumes Classic SPP will
    spend hours on Windows COM ports that were never going to appear.
    Also records which client cuts using which battery, the build and publish
    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
2026-08-06 build(desktop): MSI installer alongside the portable exe
    The published SmartSocket.exe is self-contained and runs by double-clicking,
    which is the right thing to hand over on a flash drive - nothing to install and
    no runtime to chase. This is the other case: a machine where it should live in
    Program Files, appear in the Start menu, be listed in Apps and Features, and
    uninstall cleanly.
    Same single file inside both, so they are interchangeable. This only decides
    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
2026-08-06 fix(android): scan for the socket, because a BLE module never pairs
    THE MODULE IS NOT DISCOVERABLE IN ANDROID'S BLUETOOTH SETTINGS, and it never
    will be. Bonding is optional for BLE and these serial modules do not ask for it -
    you simply connect. So an HM-10 never appears in the paired list, and an app that
    looks only at bonded devices can never find it however long the user waits.
    Scanning is the only route to it. BLUETOOTH_SCAN comes back, having been removed
    earlier when the app genuinely did list bonded devices only - correct then, wrong
    the moment the module turned out to be BLE. Declared neverForLocation because
    this is not location work; below 12 there is no such flag and the platfor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
2026-08-06 fix(android): sort scan results by signal, so the socket is findable
    A BLE sweep in a building returns dozens of results and nearly all of them are
    unnamed - phones and watches using rotating private addresses, which is what BLE
    privacy is for. A flat list of twenty 'Unnamed' rows is not a device picker.
    The socket is the thing on the desk in front of you, so it is reliably the
    loudest. Results now sort named first, then strongest first, and each row says
    roughly how far away it is. That makes the list usable without filtering by name,
    which would be wrong: the module can be renamed by whoever configured it, and
    this one is an HM-10 calling itself HC-05.
    Repeat sightings now update the ent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
2026-08-06 fix(android): say the phone is charging, since the socket cannot tell
    The socket reports READY and 'Waiting for something to be plugged in' with a
    phone charging on it, and it is not wrong: a phone draws about 20 mA on 230 V,
    below a single ADC count on the ACS712-5A and below NoiseFloorMa, so the sensor
    returns a true zero and the state machine concludes the outlet is empty.
    That is the founding premise of this app, and the screen was hiding it behind
    text that reads like a fault. Android knows the phone is charging, so when it is
    and the socket says READY, the app says so - and explains why the socket cannot.
    Also fixes the battery percentage wrapping: the longer charge-window text pushe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
2026-08-06 feat: say Charging when the socket cannot measure the load
    The socket reads a true zero with a phone charging on it - 20 mA on 230 V is
    below one ADC count on the ACS712-5A and below NoiseFloorMa - so it shows READY
    and 'waiting for something to be plugged in' over an outlet that is in use, and
    the app's largest, most confident element was a permanent 0.00 A. Both read as a
    fault. Neither is one: the sensor is blind at that size, and that blindness is
    the reason these apps exist.
    Three additions to the protocol, all display-only - nothing in the state machine
    reads them, because a socket with no client attached must behave identically:
    L<0|1> the client can see itself charging
    T<0-10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
    [HalTelemetry.cpp, SmartSocket.ino]
2026-08-06 fix(android): serialise GATT writes, and let Clear reset the socket's totals
    ANDROID ALLOWS ONE OUTSTANDING GATT WRITE PER CONNECTION. The app pushes
    battery, limit and charging state together; the first went out and the other two
    were rejected outright and silently - writeCharacteristic returns false, nothing
    is sent, and nothing tells you.
    The symptom was a convincing impersonation of a firmware bug: the LCD showed the
    battery percentage and kept saying 'Ready' over a charging phone, because B78
    arrived and L1 never did. Writes are now serialised behind a mutex and each waits
    for onCharacteristicWrite, with a timeout so a module that never acknowledges
    cannot wedge the queue.
    The lifetim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
    [HalTelemetry.cpp]
2026-08-06 feat(android): hold the link until the user says otherwise
    A phone loses this link for reasons that are all temporary - the screen goes
    off, it goes out of range, Doze quietens the radio - and the app treated every
    one of them as final. Four separate things had to change.
    RETRY FOREVER. The schedule stopped after twelve attempts, so a phone left
    charging overnight was unwatched by morning and the cutoff it was promised
    silently never happened. The escalation still ends; the trying does not. It
    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
2026-08-06 fix(android): stop scanning before connecting, and ride out spurious GATT failures
    TWO CAUSES, AND THE FIRST WAS MINE. Adding the BLE scan introduced a regression:
    the picker listed the socket and then never opened it. There is one radio, and a
    sweep running across a connectGatt starves it - on Android that is a reliable way
    to make a connection hang or time out. Everything that connects now stops looking
    first, whether the request came from the picker, from launch, or from a reboot,
    and a sweep is refused outright while a link is up or being made.
    The second is the platform. Android's GATT stack fails spuriously and often, and
    status 133 is the usual shape of it - an undocumented catch-all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
